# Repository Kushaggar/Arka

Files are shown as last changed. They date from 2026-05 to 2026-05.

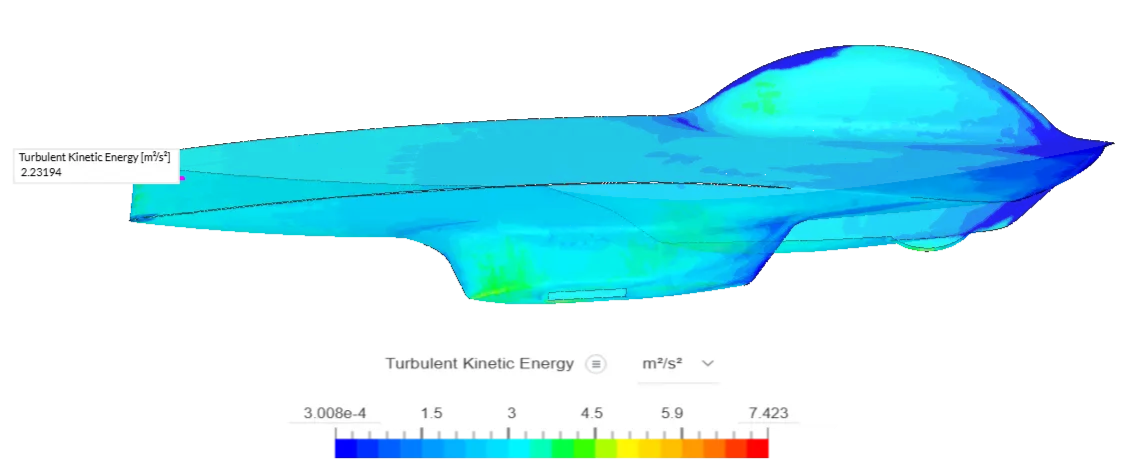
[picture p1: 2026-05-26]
aerodynamics/CFD Result (2).png

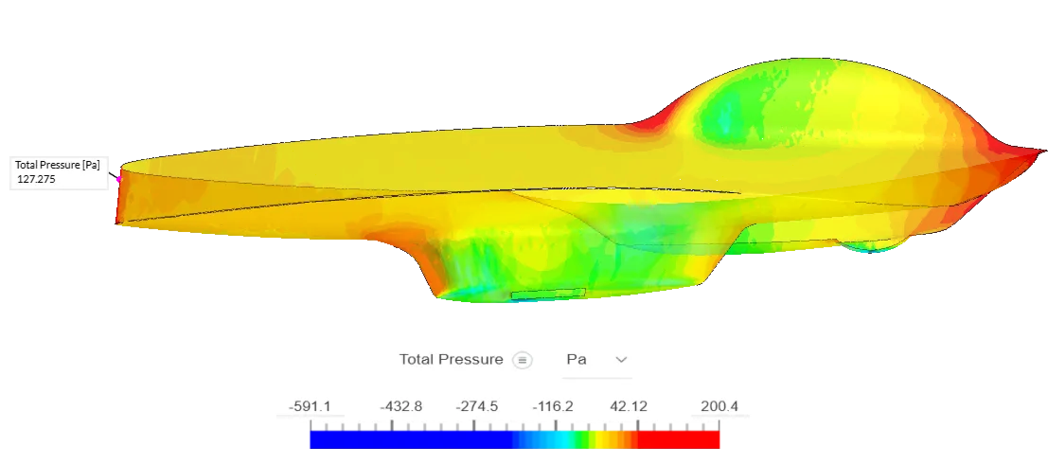
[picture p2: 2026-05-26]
aerodynamics/CFD Result (1).png

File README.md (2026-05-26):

# Arka — Solar Vehicle
**Bharat Solar Vehicle Challenge (BSVC) 2025 | Team DTU Supermileage**

Arka (Sanskrit for *the sun*) is a solar-powered race vehicle designed and built by Team DTU Supermileage 
for BSVC 2025. The entire vehicle including chassis, composite body, and aerodynamic shell, was designed 
and fabricated in approximately three weeks.

## Key Specs

| Parameter | Value |
|---|---|
| Drag Coefficient (Cd) | 0.13 |
| Chassis Mass | 32 kg |
| Torsional Rigidity | 1800 Nm/deg |
| Solar Array Area | 4 m² |
| Chassis Material | AISI 4130 Chromoly Steel |
| Body Material | E-glass / Epoxy + Soric XF core |
| Event | BSVC 2025, Coimbatore |

## Sections

- [Chassis Engineering](./chassis/README.md)
- [Aerodynamics](./aerodynamics/README.md)
- [Composites & Body](./composites/README.md)
- [Design Decisions Log](./docs/design-decisions.md)

## My Role
Head of Aerodynamics & Chassis — led a 7-member sub-team responsible for CFD-driven body design, 
spaceframe engineering, FEA validation, and composite body manufacturing.

**Portfolio:** [kushank.vercel.app/projects](https://kushank.vercel.app/projects)

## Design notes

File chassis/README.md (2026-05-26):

# Chassis Engineering

## Overview
Tubular spaceframe designed for the solar vehicle context — structural integrity without unnecessary mass.
Final chassis: **32 kg**, torsional rigidity: **1800 Nm/deg**.

## Material — Why AISI 4130 Chromoly?

Most student teams default to AISI 1018 mild steel or Al 6061-T6. We chose 4130 Chromoly for three reasons:

| Property | 4130 Chromoly | Mild Steel (1020) |
|---|---|---|
| Yield Strength | ~435 MPa | ~207 MPa |
| Fatigue Resistance | High (Cr-Mo alloying) | Moderate |
| TIG Weldability | Excellent | Good |

Same safety factor, thinner walls, less mass — that's the whole game on a solar car.

## Design & Validation
- Modelled in **SolidWorks Weldments** with real section profiles per member
- FEA run for worst-case brake, cornering, and bump load scenarios
- Torsional rigidity test: rear suspension plane fully constrained, torque applied at front, 
  angular deflection measured → **1800 Nm/deg**
- Mass tracked per member throughout; members with poor stiffness-to-mass ratio were removed 
  or rerouted to more efficient load paths

## Fabrication
Fabricated at **Mecrox Tech Pvt. Ltd., Gurugram** with on-site oversight.  
Tube notching (profiling tube ends for tight mating joints) done manually.

## CAD Files

| File | Description |
|---|---|
| `Chassis.STEP` | Full spaceframe assembly — open in SolidWorks or any STEP-compatible viewer |

The model includes real section profiles assigned to each member via SolidWorks Weldments.
Torsional rigidity and load case validations were run directly on this geometry.

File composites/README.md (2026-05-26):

# Composites & Body Manufacturing

## Why Composites?
A solar car is energy-limited. Every gram costs watt-hours. Metal body was ruled out immediately.
We built a **non-structural composite body over the spaceframe** — a deliberate choice for 
manufacturing simplicity given the vehicle's size.

## Material Selection

**Fibre: E-glass (200gsm twill)**  
Carbon fibre would have been ideal but at 5–10× the cost with no autoclave available, it was 
never realistic. For a non-structural body that just needs to hold its aerodynamic shape, 
E-glass is the right call.

**Resin: Epoxy with amine-based hardener (slow pot life)**  
Chosen over polyester for:
- Lower shrinkage: ~1–2% vs ~4–8% for polyester
- Better fibre adhesion
- Superior dimensional stability (critical for holding aero contour)  

Slow hardener = 30–45 min pot life. On large panels, fast hardener causes dry spots 
and voids before wet-out is complete.

**Core: Soric XF (polyester foam)**  
Sandwich construction: 2× 200gsm E-glass on either face of Soric XF core.  
Honeycomb core rejected — requires vacuum bagging or autoclave for proper consolidation.

## The Mould — A Cost-Constrained Innovation
Standard route: CNC-machined polyurethane foam mould. Too expensive, CNC beds hard to source in Delhi.

Our approach (inspired by boat building):
1. Laser-cut 2mm mild steel sheets as cross-sectional body profiles
2. Welded into a box frame
3. Continuous steel skin sheet welded over them as layup surface

**Result: ~1/5th the cost of the conventional foam mould route.**

Challenges encountered and solved:
- **Thermal distortion** from welding the skin sheet → worked around during layup
- **Mould flex** on 5m steel sheet → solved by welding steel angle sections along edges as a backbone

## Layup & Finishing
Hand layup process. Male mould = rough outer surface, sanded and filled post-cure.  
Upper fairing covered by solar panels — finish was a low priority relative to structural integrity.

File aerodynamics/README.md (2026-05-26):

# Aerodynamics

## The Core Equation
Solar racing is a game of energy margins. The only input is the sun (4 m² array). 
The only job is to waste as little of it as possible.

**Maximise solar input → Minimise drag loss**

## Why Aerodynamics Dominates
Aerodynamic drag scales with the **square of velocity**. Beyond a certain speed it completely 
overtakes rolling resistance. Our model confirmed aerodynamics as the single most consequential 
design domain on the car.

## Design Philosophy
Three drag components targeted: pressure drag, viscous (skin-friction) drag, and interference drag.

Strategy:
- Long forward canopy houses the 4 m² solar array
- Establishes a clean, predictable boundary layer over the main body
- Driver pod and wheel fairings shaped to perform within this pre-conditioned flow

## CFD Results

| Vehicle | Cd |
|---|---|
| Arka | **0.13** |
| Tokai Challenger (world reference) | 0.11 |

Achieved within BSVC constraints (maximise solar panel area, front-facing panel layout) 
which restricted pure aerodynamic optimisation compared to unconstrained monohull designs.

**35% reduction in Cd** achieved through iterative CFD validation across design cycles.

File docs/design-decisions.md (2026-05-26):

# Key Design Decisions

A log of the 4 biggest engineering calls made on Arka and the reasoning behind each.

## 1. AISI 4130 Chromoly over Mild Steel
Higher cost, harder to source. Chosen for ~2× yield strength, better fatigue life under 
cyclic race loads, and clean TIG weld behaviour. Enabled thinner walls at the same safety 
factor — net mass saving justified the premium.

## 2. E-glass over Carbon Fibre
Carbon fibre at 5–10× the cost with no autoclave = not realistic for a student team on a 
tight budget. Body is non-structural. E-glass meets the brief: light, stiff enough to hold 
aero shape, hand-layup compatible.

## 3. Steel Mould over CNC Foam Mould
CNC machining of a 5m polyurethane foam mould is expensive and hard to source in Delhi. 
Laser-cut steel cross-sections welded into a box frame with a skin sheet achieved a functional 
mould at ~1/5th the cost. Introduced thermal distortion and weight challenges that were 
solved on-site.

## 4. Non-Structural Body over Monocoque
A monocoque would integrate body and structure but is far harder to manufacture without 
precision tooling. Separating the spaceframe (structural) from the composite body 
(aerodynamic shell) simplified fabrication significantly given our 3-week timeline.

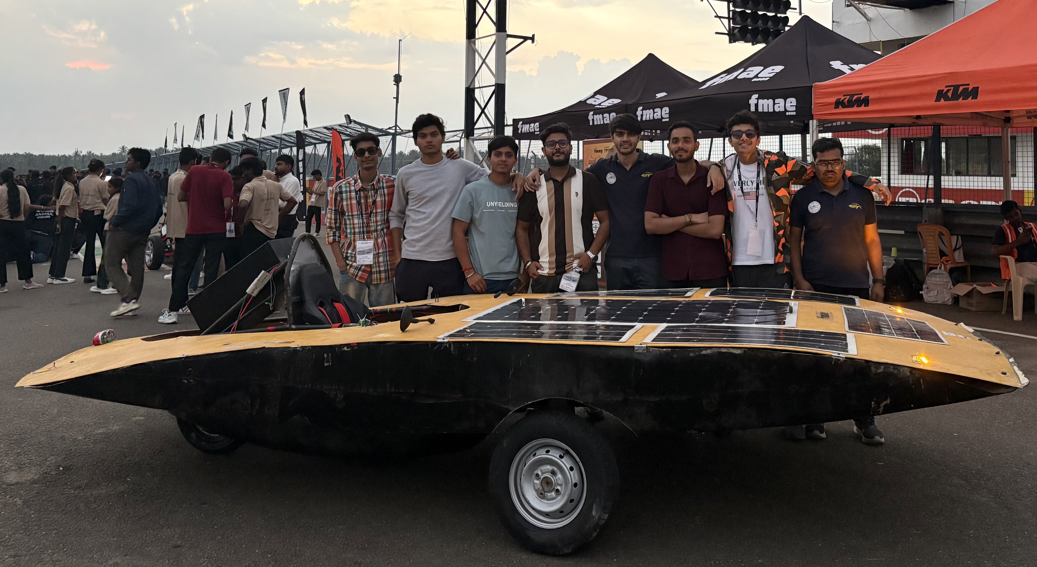
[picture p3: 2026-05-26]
team_photo.jpeg

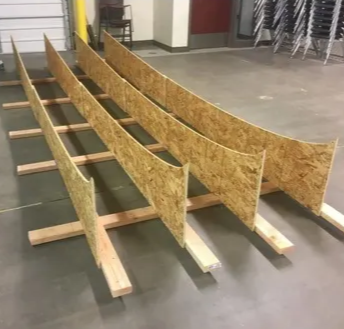
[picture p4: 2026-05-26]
composites/composite2.png

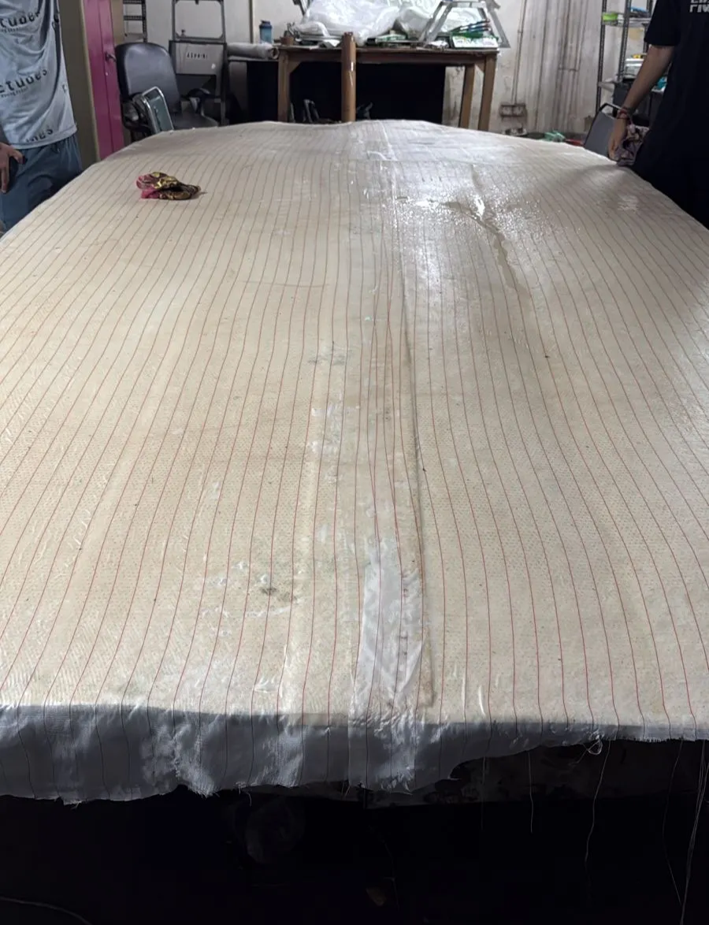
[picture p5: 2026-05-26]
composites/composite5.png

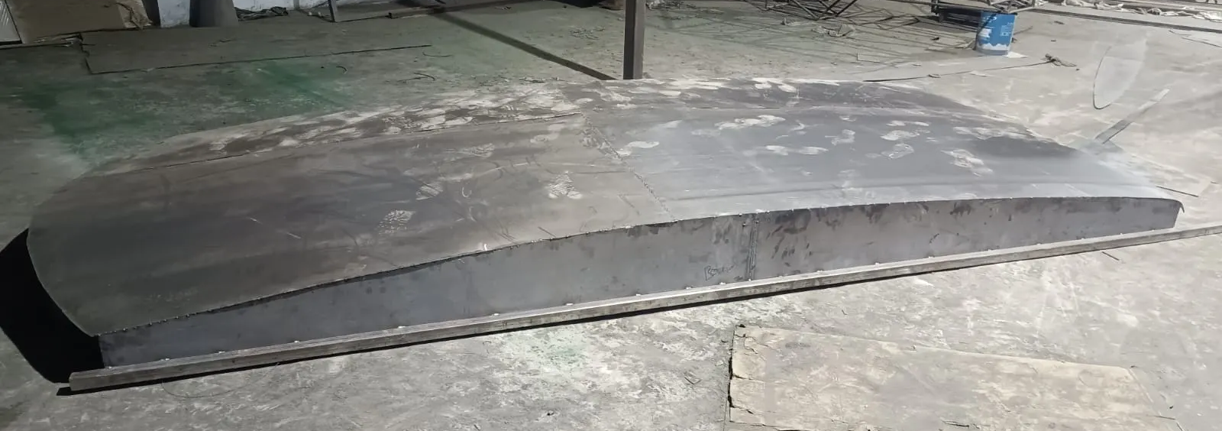
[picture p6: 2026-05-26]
composites/composite3.png

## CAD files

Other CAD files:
chassis/Chassis.STEP
